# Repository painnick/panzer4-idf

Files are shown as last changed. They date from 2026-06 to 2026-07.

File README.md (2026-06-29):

# RC 탱크 프로젝트(Panzer IV)

Bluepad32를 이용한 게임패드 조작 RC 탱크입니다. ESP32-IDF(v5.5.2) 기반으로 개발되었습니다.

PCB는 KingTiger용을 사용합니다.

## 주요 기능

- **게임패드 연결**: Bluepad32를 통한 블루투스 게임패드 연결 및 상태 LED/진동 피드백
- **트랙 제어**: 좌측 스틱 Y축(좌측 트랙), 우측 스틱 Y축(우측 트랙) 독립 제어 (DRV8833, MCPWM, 엑스포 곡선, 가감속 램프, 대회전 감속)
- **터렛 제어**: D-PAD 좌우로 터렛 회전 (DRV8833, MCPWM, 최대 속도 100% 듀티)
- **포 마운트 제어**: D-PAD 상하로 포신 상하 이동 (SG90 서보, 80~110도, 초당 10도)
- **포신 발사**: B 버튼 클릭 시 포신 반동(서보 0->60->0), LED 점등, 발사 효과음 및 게임패드 진동 발생 (트랙 후진 반동 200ms 동기화)
- **기관총 발사**: A 버튼 클릭 시 기관총 LED 깜빡임(500ms), 효과음 및 게임패드 진동 발생 (반응성 개선을 위해 지연 시간 300ms로 단축)
- **헤드라이트**: Y 버튼으로 헤드라이트 ON/OFF 토글
- **볼륨 조절**: L1 버튼으로 감소, R1 버튼으로 증가 (NVS 저장, 10-30 범위)
- **대기 상태 알림**: 게임패드 연결 전/해제 후에는 30초마다 엔진 IDLE 효과음을 1회 재생하여 상태 알림 (연결 중에는 IDLE 소리 중지)
- **설정 초기화**: Select + Start 버튼을 3초간 누르면 볼륨 설정 초기화 및 재시작

## 하드웨어 구성

### ESP32 핀 맵

| ESP32 핀 | 기능 | 설명 |
| :--- | :--- | :--- |
| **GPIO 4** | 후미등 LED | Backlight |
| **GPIO 5** | 헤드라이트 LED | Headlight (Y 버튼 토글) |
| **GPIO 13** | 포 마운트 서보 | SG90 서보 - 포신 상하 이동 (80~110도) |
| **GPIO 16** | 기관총 LED | MG LED (A 버튼 클릭 시 깜빡임) |
| **GPIO 17** | 포신 LED | Gun LED (B 버튼 클릭 시 점등) |
| **GPIO 21** | 터렛 IN2 | DRV8833 - 터렛 회전 (MCPWM) |
| **GPIO 22** | 터렛 IN1 | DRV8833 - 터렛 회전 (MCPWM) |
| **GPIO 23** | 사운드 TX | DFPlayer Mini UART TX |
| **GPIO 25** | 우측 트랙 IN2 | DRV8833 - 우측 트랙 (MCPWM) |
| **GPIO 26** | 좌측 트랙 IN2 | DRV8833 - 좌측 트랙 (MCPWM) |
| **GPIO 27** | 좌측 트랙 IN1 | DRV8833 - 좌측 트랙 (MCPWM) |
| **GPIO 32** | 포신 서보 | 포신 반동 (Recoil) 제어 |
| **GPIO 33** | 우측 트랙 IN1 | DRV8833 - 우측 트랙 (MCPWM) |

### 모터 드라이버 (DRV8833) 연결

#### 트랙 드라이버
- **AIN (27, 26)**: 좌측 트랙 모터 (MCPWM)
- **BIN (33, 25)**: 우측 트랙 모터 (MCPWM)

#### 터렛 드라이버
- **AIN (22, 21)**: 터렛 회전 모터 (MCPWM, 최대 속도 100% 듀티)

### 서보 모터
- **GPIO 32**: 포신 반동 서보 (B 버튼 시 0도 -> 60도 -> 0도 동작)
- **GPIO 13**: 포 마운트 서보 SG90 (D-PAD 상하, 80~110도 범위, 초기 90도)

### 사운드 모듈 (DFPlayer Mini)
- **TX (GPIO 23)**: 모듈의 RX 핀에 연결하여 UART 제어 (9600bps)
- **RX (NC)**: 현재 수신 핀이 연결되지 않아 모듈 피드백(재생 종료 알림 등) 대신 타이머/하드웨어 루프 명령어로 상태 제어

---

## 게임패드 조작법

| 조작 | 기능 | 상세 동작 |
| :--- | :--- | :--- |
| **좌측 스틱 Y** | 좌측 트랙 | 위(전진), 아래(후진) |
| **우측 스틱 Y** | 우측 트랙 | 위(전진), 아래(후진) |
| **D-PAD 좌/우** | 터렛 회전 | 좌우 회전 (MCPWM, 최대 속도) |
| **D-PAD 상/하** | 포 마운트 | 상하 이동 (SG90 서보, 80~110도) |
| **A 버튼** | 기관총 발사 | 효과음 재생 + MG LED 깜빡임 |
| **B 버튼** | 주포 발사 | 효과음 재생 + Gun LED 점등 + 서보 반동 |
| **Y 버튼** | 헤드라이트 | ON / OFF 토글 |
| **L1 / R1** | 볼륨 조절 | 볼륨 감소 / 증가 (NVS 자동 저장) |
| **Select + Start** | 시스템 초기화 | 3초간 입력 시 설정 초기화 및 재부팅 |

---

## 소프트웨어 구조

### 주요 컴포넌트 (`components/rctank/`)
- `rctank_motor`: MCPWM을 이용한 트랙 및 터렛 제어
- `rctank_servo`: LEDC를 이용한 포신 반동 서보 및 포 마운트(SG90) 서보 제어
- `rctank_led`: 각종 LED 상태 제어
- `rctank_dfplayer`: DFPlayer Mini 제어 및 효과음 재생
- `rctank_storage`: NVS를 이용한 볼륨 및 설정값 저장

### 플랫폼 로직 (`main/my_flatform.c`)
- Bluepad32 이벤트 핸들링 및 게임패드 입력 맵핑
- **Core 1 오프로딩**: 게임패드 입력을 큐로 전달하여 Core 1에서 모터/서보/버튼 처리 (BT 컨트롤러 부하 경감)
- 발사 시퀀스 지연 보정 (Sound 재생 시점과 하드웨어 동작 동기화)
- 대회전 감속: 좌우 트랙 속도 차이가 클 때 전체 속도 비례 감소 (`TURN_SLOWDOWN_FACTOR`)

### 트랙 속도 제어 (`components/rctank/rctank_motor.c`)
- **엑스포 곡선**: 스틱 저속 구간(0~90%)에서 모터 속도를 완만하게, 고속 구간에서 급격하게 매핑하여 미세 조향 응답성 향상
- **가감속 램프**: 10ms 주기로 현재 속도를 목표 속도로 점진적 변화 (가속 600/sec, 감속 1000/sec)
- **최소 기동 속도**: 정지 상태에서 모터 기동 시 최소 토크 확보를 위한 오프셋 적용
- **감속 제자리 정지**: 감속 중 최소 속도 이하로 떨어지면 즉시 정지하여 모터 험 노이즈 방지

## 속도 제어 설정값

| 상수 | 값 | 위치 | 설명 |
| :--- | :--- | :--- | :--- |
| `AXIS_DEADZONE` | 60 | `my_flatform.c` | 조이스틱 데드존 (이 값 이하 무시) |
| `AXIS_MAX` | 512 | `my_flatform.c` | 조이스틱 최대 축 값 |
| `TURN_SLOWDOWN_FACTOR` | 60 | `my_flatform.c` | 대회전 시 최소 속도 비율 (60 = 60%) |
| `TRACK_DECEL_STEP` | 16 | `rctank_motor.c` | 10ms 당 감속 단계 (약 400ms 내 정지) |
| `TRACK_ACCEL_STEP` | 6 | `rctank_motor.c` | 10ms 당 가속 단계 (약 1000ms 내 최대 속도) |
| `TRACK_MIN_SPEED` | 448 | `rctank_motor.c` | 모터 최소 기동 속도 오프셋 |
| `TRACK_STICK_THRESHOLD` | 460 | `rctank_motor.c` | 엑스포 곡선 저속/고속 구간 경계 (90%) |
| `TRACK_EXPO_THRESHOLD` | 178 | `rctank_motor.c` | 경계값에서의 모터 속도 (약 35%) |

## 개발 환경 설정

1. **ESP-IDF v5.5.2** 설치
2. 프로젝트 루트의 `env.bat`를 실행하여 환경 변수 설정 (Windows)
3. `idf.py build` 명령으로 컴파일
4. `idf.py flash monitor` 명령으로 업로드 및 로그 확인

## 라이센스
MIT License

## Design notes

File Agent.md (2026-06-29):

# 프로젝트 컨텍스트: ESP32-IDF 기반 시스템 개발

이 파일은 AI 에이전트가 본 프로젝트의 구조, 스타일 가이드 및 기술적 의사결정 사항을 이해하기 위한 가이드라인입니다.

## 🛠 기술 스택
- **Framework:** ESP-IDF v5.5.2
- **Language:** C (C99/C11 표준 지향)
- **Build System:** CMake / idf.py. 루트의 env.bat를 먼저 실행하여 IDF 환경 설정을 반영해야 함 
- **Target Chip:** ESP32-기본

## 📂 프로젝트 구조
- `main/`: 메인 로직 및 `app_main.c` 위치
- `components/`: 재사용 가능한 사용자 정의 컴포넌트
- `managed_components/`: IDF Component Manager를 통해 추가된 라이브러리
- `sdkconfig`: ESP-IDF 구성 설정 파일

## 📝 코딩 스타일 및 규칙
1. **Naming Convention:**
    - 함수/변수: `snake_case` (예: `sensor_read_task`)
    - 컴포넌트 접두사: 함수명 앞에 컴포넌트 이름을 붙임 (예: `wifi_init_sta()`)
    - 상수/매크로: `UPPER_SNAKE_CASE`
2. **Error Handling:**
    - 모든 ESP-IDF API 호출 시 `esp_err_t` 리턴값을 확인하고 `ESP_ERROR_CHECK()` 또는 적절한 로그 처리를 수행할 것.
3. **Logging:**
    - `printf` 대신 `ESP_LOGI`, `ESP_LOGE`, `ESP_LOGW` 매크로를 사용할 것. (Tag는 파일 상단에 정의)
4. **FreeRTOS 활용:**
    - Task 생성 시 Stack Size와 Priority를 명시적으로 관리할 것.
    - 공유 자원 접근 시 `Mutex` 또는 `Semaphore` 필수 사용.

## 🔗 참조할 기존 코드 패턴 (Reference)
- **NVS 저장:** `components/storage/nvs_helper.c`의 패턴 사용
- **메모리 관리:** 정적 할당보다는 `pvPortMalloc` 또는 `heap_caps_malloc` 사용 선호

## ⚙️ 하드웨어 제어 규칙
- **DC 모터 구동:** 트랙 및 터렛 제어는 `MCPWM`을 사용함. 터렛 회전 속도 조절은 `my_flatform.c`의 `TURRET_SPEED` 매크로로 제어 (현재 최대 속도인 511로 설정됨).
- **서보 모터:** **`LEDC`**를 사용하여 제어할 것. 포신 반동(GPIO 32) 및 포 마운트(SG90, GPIO 13) 모두 LEDC 채널 0/1을 사용.
- **입력 처리 아키텍처:** 게임패드 입력은 `my_platform_on_controller_data`(Core 0, BT 태스크)에서 큐(`input_queue`)로 전달하고, `input_process_task`(Core 1)에서 모터/서보/버튼 처리를 수행함. Core 0의 BT 컨트롤러 부하를 경감하기 위함. 모터 함수(`rctank_motor_*_set`)는 뮤텍스 없이 volatile 변수에 직접 쓰며, `_immediate` 함수는 non-blocking(timeout 0)으로 동작함.
- **동기화:** `recoil_end_time`은 `portMUX_TYPE` 스프록으로 보호하여 Core 1과 타이머 콜백 간 안전하게 공유함.

## ⚠️ 주의 사항
- `sdkconfig`를 직접 수정하지 말고, 설정 변경이 필요하면 `menuconfig` 항목을 언급해줄 것.
- IDF 5.5.2 버전의 API를 사용할 것. 다른 버전은 고려하지 않고 있음
- **하드웨어 핀(Pin) 맵 및 상세 기능 정의는 프로젝트 루트의 `README.md` 파일을 최우선으로 참조할 것.**
- **리코일 사양:** 서보 각도는 0(Rest) ~ 60(Pull) 범위를 사용하며, 트랙 후진 반동 시간은 200ms를 유지함.
- **사운드 피드백 제약:** 사운드 모듈의 RX 핀이 연결되지 않은 상태이므로, `rctank_dfplayer`의 자동 복구 기능 대신 `main` 로직의 타이머나 모듈 자체 루프 명령을 사용하여 상태를 동기화함.

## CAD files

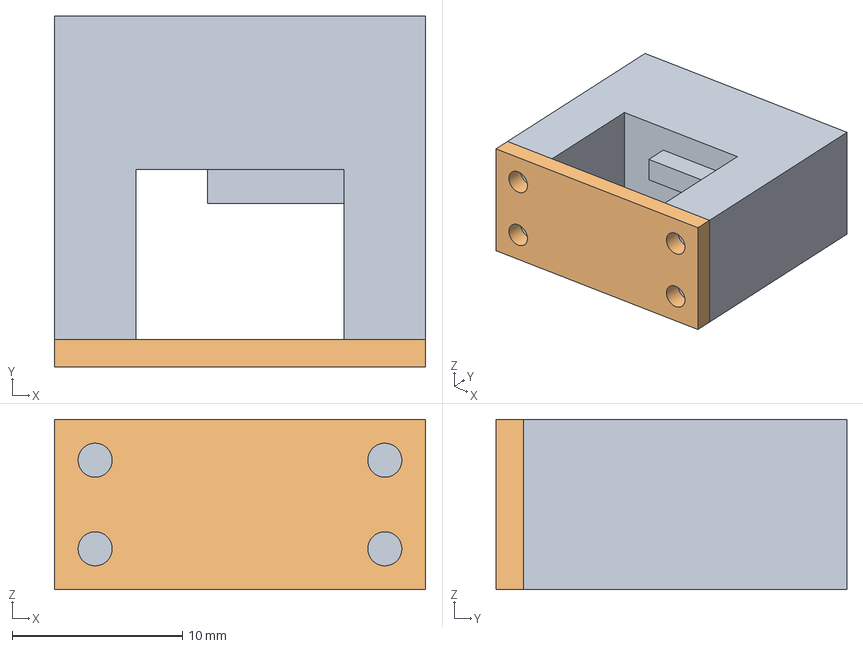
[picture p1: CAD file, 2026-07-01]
3dp/Turret Motor Guide2.step
21.8 x 20.6 x 10.0 mm

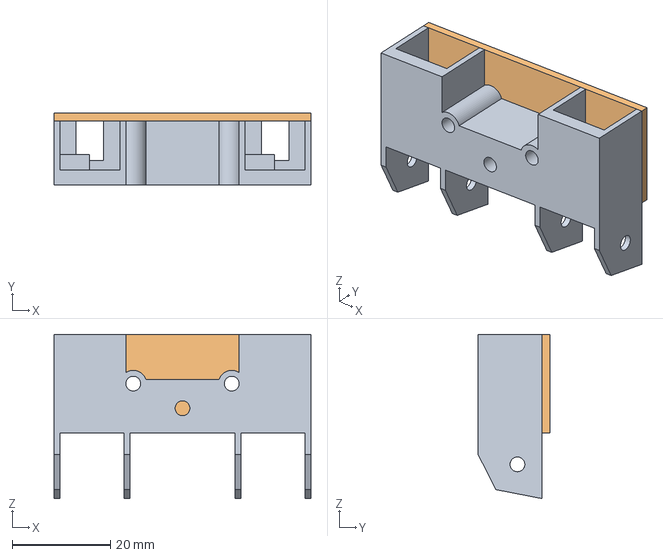
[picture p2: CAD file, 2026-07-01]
3dp/Sproket Guide.step
52.2 x 14.6 x 33.3 mm

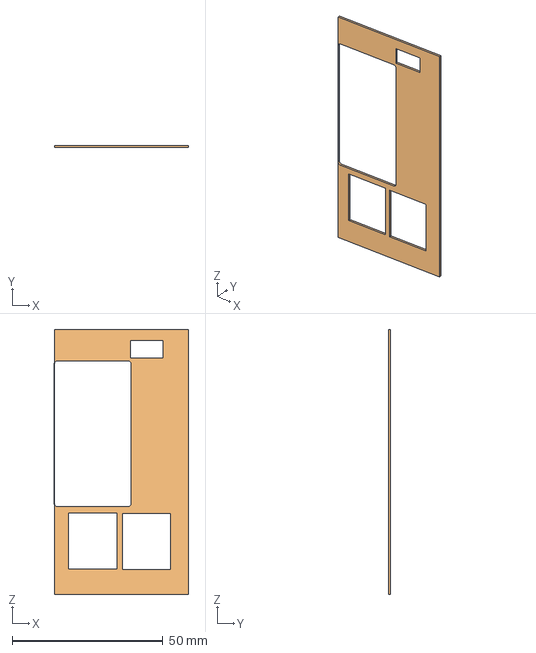
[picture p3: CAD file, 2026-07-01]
3dp/PCB 1.2.step
44.5 x 0.8 x 87.8 mm

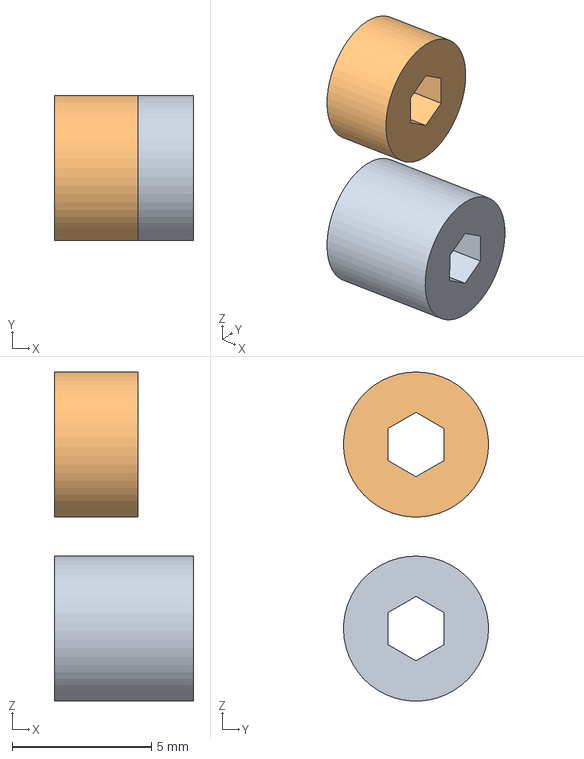
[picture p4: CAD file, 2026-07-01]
3dp/Motor Guide 2mm.step
5.00 x 5.20 x 11.8 mm

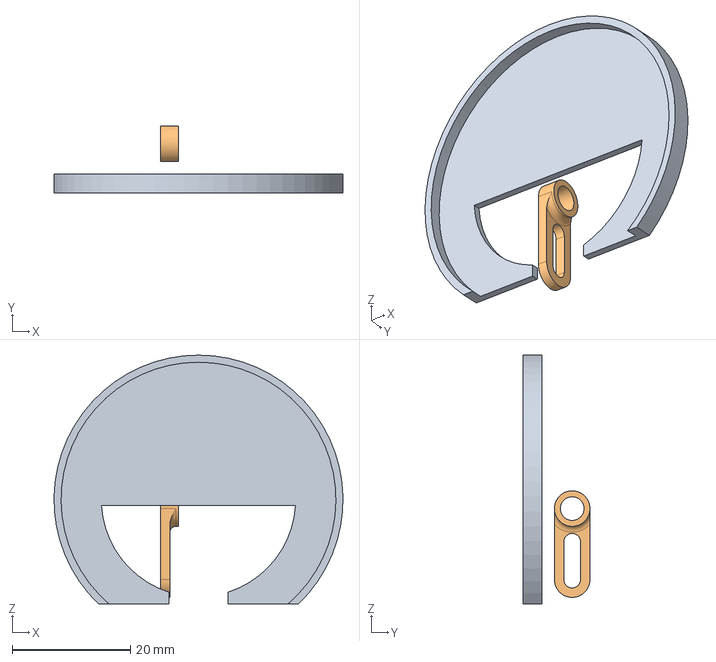
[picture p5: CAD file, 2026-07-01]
3dp/Cannon Mount.step
48.8 x 11.3 x 42.0 mm

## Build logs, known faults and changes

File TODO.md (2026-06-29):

# TODO

## ~컨트롤러 종류별 최대 입력 값 적용~

~각 컨트롤러마다 아날로그 입력 값의 최대치가 상이함~

~트랙 이동 속도에 영향을 주므로 비례 제어를 위해 컨트롤러 별 최대값 대응이 필요~

스틱 데드존을 뺀 나머지 입력 영역을 실제 트랙 이동 가능한 모터 듀티 범위와 비례하도록 처리

## 헤드 라이트 입력 조건 수정

안드로이드 게임 패드에서 L2/R2 입력 불가

PS3 무선 컨트롤러는 입력 가능

2025.12.07 우선 대응 버튼 변경

## 트랙 이동 시, 처음부터 최대값으로 이동하지 않도록 처리(Soft-start)

모터 구동 시 소모 전류가 급격하게 증가하여 극벽한 변화 시 Brownout 현상이 발생

그리고, 급출발이 현실적이지 않음

아래와 같은 아이디어가 존재

1. 500ms 내 일정 속도 이상 증가를 막는 방법
2. 기어 변속 같은 느낌으로 속도 제어
+
+## ✅ 완료된 작업
+
+### 리코일 및 기관총 시퀀스 튜닝 (2026.04.29)
+- 리코일 서보 동작 방향 반전 (90 -> 180 -> 90)
+- 트랙 반동 시간(300ms) 및 보호 로직(`recoil_end_time`) 적용
+- 기관총 발사 지연 시간(300ms) 및 점멸 시간(500ms) 최적화
+
+### 모터 제어 최적화
+- ESP32 MCPWM 자원 부족 문제 해결을 위해 터렛/포 마운트 모터를 GPIO 제어 방식으로 전환
+

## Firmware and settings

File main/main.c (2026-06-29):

// Example file - Public Domain
// Need help? http://bit.ly/bluepad32-help

#include <stdlib.h>

#include <btstack_port_esp32.h>
#include <btstack_run_loop.h>
#include <btstack_stdio_esp32.h>
#include <hci_dump.h>
#include <hci_dump_embedded_stdout.h>
#include <uni.h>

#include "sdkconfig.h"

// Sanity check
#ifndef CONFIG_BLUEPAD32_PLATFORM_CUSTOM
#error "Must use BLUEPAD32_PLATFORM_CUSTOM"
#endif

// Defined in my_platform.c
struct uni_platform* get_my_platform(void);

int app_main(void) {
    // If you enable HCI Dump better to disable "Bluepad32 USB Console" from "idf.py menuconfig".
    // hci_dump_init(hci_dump_embedded_stdout_get_instance());

    // Configure BTstack for ESP32 VHCI Controller
    btstack_init();

    // Must be called before uni_init()
    uni_platform_set_custom(get_my_platform());

    // Init Bluepad32.
    uni_init(0 /* argc */, NULL /* argv */);

    // Does not return.
    btstack_run_loop_execute();

    return 0;
}

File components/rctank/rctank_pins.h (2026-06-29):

/**
 * @file rctank_pins.h
 * @brief RC Tank 핀 정의 (README.md 기준)
 */
#ifndef RCTANK_PINS_H
#define RCTANK_PINS_H

#include "driver/gpio.h"

#ifdef __cplusplus
extern "C" {
#endif

/* LED */
#define RCTANK_PIN_GUN_LED (GPIO_NUM_17)
#define RCTANK_PIN_HEADLIGHT (GPIO_NUM_5)
#define RCTANK_PIN_MG_LED (GPIO_NUM_16) /* 기관총 LED (A 버튼, 1초간 깜빡임) */
#define RCTANK_PIN_BACKLIGHT (GPIO_NUM_4)

/* 좌측 트랙 DRV8833 (AIN1, AIN2) */
#define RCTANK_PIN_LEFT_IN1 (GPIO_NUM_27)
#define RCTANK_PIN_LEFT_IN2 (GPIO_NUM_26)

/* 우측 트랙 DRV8833 (BIN1, BIN2) */
#define RCTANK_PIN_RIGHT_IN1 (GPIO_NUM_33)
#define RCTANK_PIN_RIGHT_IN2 (GPIO_NUM_25)

/* 터렛 DRV8833 (MCPWM 제어) */
#define RCTANK_PIN_TURRET_IN1 (GPIO_NUM_22)
#define RCTANK_PIN_TURRET_IN2 (GPIO_NUM_21)

/* 포 마운트 서보 (SG90) */
#define RCTANK_PIN_SERVO_ELEVATION (GPIO_NUM_13)

/* 서보: 포신(당기기) */
#define RCTANK_PIN_SERVO_RECOIL (GPIO_NUM_32)

/* Sound (JQ6900/JQ6500) UART TX */
#define RCTANK_PIN_SOUND_TX (GPIO_NUM_23)
#define RCTANK_PIN_SOUND_RX (GPIO_NUM_NC)

#ifdef __cplusplus
}
#endif

#endif /* RCTANK_PINS_H */

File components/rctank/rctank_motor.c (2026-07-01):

/**
 * @file rctank_motor.c
 * @brief RC Tank MCPWM 트랙/터렛 제어
 */
#include "rctank_motor.h"
#include "rctank_pins.h"

#include "driver/mcpwm_prelude.h"
#include "esp_log.h"
#include "esp_check.h"

#include "freertos/FreeRTOS.h"
#include "freertos/task.h"
#include "freertos/semphr.h"

static const char *TAG = "rctank_motor";

#define MCPWM_FREQ_HZ          (20000)
#define MCPWM_RESOLUTION_HZ   (1000000)
#define MCPWM_PERIOD_TICKS    (MCPWM_RESOLUTION_HZ / MCPWM_FREQ_HZ)

/* 스틱 범위 ±512 → 듀티 비율 (0~100%) */
#define AXIS_MAX              512

#define TRACK_DECEL_STEP 16  // 10ms 당 감속 단계 (실질 범위 448~512에서 약 400ms 내에 정지, 10배 스케일)
#define TRACK_ACCEL_STEP 6   // 10ms 당 가속 단계 (실질 범위 448~512에서 약 1000ms 내에 최대 속도 도달, 10배 스케일)
#define TRACK_MIN_SPEED  448 // 모터 구동을 개시하는 최소 기동 속도 오프셋 (0~512 범위 내)
#define TRACK_STICK_THRESHOLD 460  // 90% 스틱 경계값 (512 * 0.90)
#define TRACK_EXPO_THRESHOLD  178  // 90% 경계값에서의 모터 중간 속도 목표치 (최대 속도의 약 91%가 되도록 조정)

static mcpwm_cmpr_handle_t left_cmpr_a = NULL;
static mcpwm_cmpr_handle_t left_cmpr_b = NULL;
static mcpwm_cmpr_handle_t right_cmpr_a = NULL;
static mcpwm_cmpr_handle_t right_cmpr_b = NULL;
static mcpwm_cmpr_handle_t turret_cmpr_a = NULL;
static mcpwm_cmpr_handle_t turret_cmpr_b = NULL;

static mcpwm_timer_handle_t timer0 = NULL;

static volatile int32_t target_left_speed = 0;
static volatile int32_t target_right_speed = 0;
static int32_t current_left_speed = 0;
static int32_t current_right_speed = 0;

static SemaphoreHandle_t motor_mutex = NULL;
static TaskHandle_t motor_task_handle = NULL;

static void set_motor_duty(mcpwm_cmpr_handle_t cmpr_a, mcpwm_cmpr_handle_t cmpr_b, int32_t speed);

static void update_motor_speed(int32_t *current, int32_t target)
{
    int32_t cur = *current;
    if (cur == target) {
        return;
    }

    // 1. 0에서 기동할 때 최소 구동 속도(TRACK_MIN_SPEED * 10)로 즉시 점프
    if (cur == 0 && target != 0) {
        int32_t sign = (target > 0) ? 1 : -1;
        int32_t start_speed = sign * TRACK_MIN_SPEED * 10;
        
        int32_t target_abs = (target > 0) ? target : -target;
        // target 절대값이 최소 기동 속도 이하이면 즉시 target으로 설정 후 리턴
        if (target_abs <= TRACK_MIN_SPEED * 10) {
            *current = target;
            return;
        }
        cur = start_speed;
        *current = cur;
    }

    int32_t diff = target - cur;
    int32_t step;

    // Determine if we are accelerating or decelerating
    bool is_decelerating = false;
    
    if (cur > 0) {
        if (target < cur) {
            is_decelerating = true;
        }
    } else if (cur < 0) {
        if (target > cur) {
            is_decelerating = true;
        }
    } else {
        is_decelerating = false;
    }

    if (is_decelerating) {
        step = TRACK_DECEL_STEP;
    } else {
        step = TRACK_ACCEL_STEP;
    }

    if (diff > 0) {
        if (diff > step) {
            *current = cur + step;
        } else {
            *current = target;
        }
    } else {
        if (-diff > step) {
            *current = cur - step;
        } else {
            *current = target;
        }
    }

    // 2. 감속 정지 시 최소 구동 속도 이하로 떨어지면 웅웅거림 방지를 위해 즉시 0으로 정지
    if (target == 0) {
        int32_t cur_abs = (*current > 0) ? *current : -*current;
        if (cur_abs < TRACK_MIN_SPEED * 10) {
            *current = 0;
        }
    }
}

static void rctank_motor_update_task(void *pvParameters)
{
    TickType_t last_wake_time = xTaskGetTickCount();
    while (1) {
        if (motor_mutex && xSemaphoreTake(motor_mutex, portMAX_DELAY) == pdTRUE) {
            update_motor_speed(&current_left_speed, target_left_speed * 10);
            if (left_cmpr_a && left_cmpr_b) {
                set_motor_duty(left_cmpr_a, left_cmpr_b, current_left_speed / 10);
            }

            update_motor_speed(&current_right_speed, target_right_speed * 10);
            if (right_cmpr_a && right_cmpr_b) {
                set_motor_duty(right_cmpr_a, right_cmpr_b, current_right_speed / 10);
            }
            xSemaphoreGive(motor_mutex);
        }
        vTaskDelayUntil(&last_wake_time, pdMS_TO_TICKS(10));
    }
}

static void set_motor_duty(mcpwm_cmpr_handle_t cmpr_a, mcpwm_cmpr_handle_t cmpr_b, int32_t speed)
{
    uint32_t ticks;
    if (speed > 0) {
        ticks = ((uint32_t)speed * MCPWM_PERIOD_TICKS) / AXIS_MAX;
        if (ticks > MCPWM_PERIOD_TICKS) ticks = MCPWM_PERIOD_TICKS;
        ESP_ERROR_CHECK(mcpwm_comparator_set_compare_value(cmpr_a, ticks));
        ESP_ERROR_CHECK(mcpwm_comparator_set_compare_value(cmpr_b, 0));
    } else if (speed < 0) {
        ticks = ((uint32_t)(-speed) * MCPWM_PERIOD_TICKS) / AXIS_MAX;
        if (ticks > MCPWM_PERIOD_TICKS) ticks = MCPWM_PERIOD_TICKS;
        ESP_ERROR_CHECK(mcpwm_comparator_set_compare_value(cmpr_a, 0));
        ESP_ERROR_CHECK(mcpwm_comparator_set_compare_value(cmpr_b, ticks));
    } else {
        ESP_ERROR_CHECK(mcpwm_comparator_set_compare_value(cmpr_a, 0));
        ESP_ERROR_CHECK(mcpwm_comparator_set_compare_value(cmpr_b, 0));
    }
}
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

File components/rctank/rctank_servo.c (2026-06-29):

/**
 * @file rctank_servo.c
 * @brief RC Tank LEDC 서보 제어
 */
#include "rctank_servo.h"
#include "rctank_pins.h"

#include "driver/ledc.h"
#include "esp_log.h"

static const char* TAG = "rctank_servo";

#define LEDC_TIMER LEDC_TIMER_0
#define LEDC_MODE LEDC_LOW_SPEED_MODE
#define LEDC_DUTY_RES LEDC_TIMER_10_BIT
#define LEDC_FREQ_HZ 50

#define SERVO_PULSE_MIN_US 500
#define SERVO_PULSE_MAX_US 2500
#define SERVO_DEGREE_RANGE 180

static uint32_t degree_to_duty(int degree) {
    if (degree < 0)
        degree = 0;
    if (degree > SERVO_DEGREE_RANGE)
        degree = SERVO_DEGREE_RANGE;
    uint32_t us =
        SERVO_PULSE_MIN_US + (SERVO_PULSE_MAX_US - SERVO_PULSE_MIN_US) * (uint32_t)degree / SERVO_DEGREE_RANGE;
    uint32_t max_duty = (1 << LEDC_DUTY_RES) - 1;
    return (us * LEDC_FREQ_HZ * max_duty) / 1000000;
}

esp_err_t rctank_servo_init(void) {
    ledc_timer_config_t timer_config = {
        .speed_mode = LEDC_MODE,
        .duty_resolution = LEDC_DUTY_RES,
        .timer_num = LEDC_TIMER,
        .freq_hz = LEDC_FREQ_HZ,
        .clk_cfg = LEDC_AUTO_CLK,
    };
    esp_err_t ret = ledc_timer_config(&timer_config);
    if (ret != ESP_OK) {
        ESP_LOGE(TAG, "ledc_timer_config %s", esp_err_to_name(ret));
        return ret;
    }

    ledc_channel_config_t ch_config = {
        .gpio_num = RCTANK_PIN_SERVO_RECOIL,
        .speed_mode = LEDC_MODE,
        .channel = LEDC_CHANNEL_0,
        .timer_sel = LEDC_TIMER,
        .duty = degree_to_duty(RCTANK_SERVO_GUN_DEG_REST),
        .hpoint = 0,
    };
    ret = ledc_channel_config(&ch_config);
    if (ret != ESP_OK) {
        ESP_LOGE(TAG, "ledc_channel_config recoil %s", esp_err_to_name(ret));
        return ret;
    }

    ledc_channel_config_t elevation_ch_config = {
        .gpio_num = RCTANK_PIN_SERVO_ELEVATION,
        .speed_mode = LEDC_MODE,
        .channel = LEDC_CHANNEL_1,
        .timer_sel = LEDC_TIMER,
        .duty = degree_to_duty(RCTANK_SERVO_ELEVATION_DEG_REST),
        .hpoint = 0,
    };
    ret = ledc_channel_config(&elevation_ch_config);
    if (ret != ESP_OK) {
        ESP_LOGE(TAG, "ledc_channel_config elevation %s", esp_err_to_name(ret));
        return ret;
    }

    rctank_servo_gun_set_degree(RCTANK_SERVO_GUN_DEG_REST);
    rctank_servo_elevation_set_degree(RCTANK_SERVO_ELEVATION_DEG_REST);
    ESP_LOGI(TAG, "servo init ok (recoil pin %d, elevation pin %d)", RCTANK_PIN_SERVO_RECOIL, RCTANK_PIN_SERVO_ELEVATION);
    return ESP_OK;
}

static int s_gun_degree = RCTANK_SERVO_GUN_DEG_REST;
static int s_elevation_degree = RCTANK_SERVO_ELEVATION_DEG_REST;

void rctank_servo_gun_set_degree(int degree) {
    if (degree < 0)
        degree = 0;
    if (degree > SERVO_DEGREE_RANGE)
        degree = SERVO_DEGREE_RANGE;
    s_gun_degree = degree;
    uint32_t duty = degree_to_duty(degree);
    ledc_set_duty(LEDC_MODE, LEDC_CHANNEL_0, duty);
    ledc_update_duty(LEDC_MODE, LEDC_CHANNEL_0);
}

void rctank_servo_gun_enable(int enable) {
    if (enable) {
        /* 저장된 각도로 duty 복원 */
        rctank_servo_gun_set_degree(s_gun_degree);
    } else {
        /* PWM 중지 -> 서보 힘 풀림 */
        ledc_stop(LEDC_MODE, LEDC_CHANNEL_0, 0);
    }
}

void rctank_servo_elevation_set_degree(int degree) {
    if (degree < RCTANK_SERVO_ELEVATION_MIN)
        degree = RCTANK_SERVO_ELEVATION_MIN;
    if (degree > RCTANK_SERVO_ELEVATION_MAX)
        degree = RCTANK_SERVO_ELEVATION_MAX;
    s_elevation_degree = degree;
    uint32_t duty = degree_to_duty(degree);
    ledc_set_duty(LEDC_MODE, LEDC_CHANNEL_1, duty);
    ledc_update_duty(LEDC_MODE, LEDC_CHANNEL_1);
}

void rctank_servo_elevation_enable(int enable) {
    if (enable) {
        rctank_servo_elevation_set_degree(s_elevation_degree);
    } else {
        ledc_stop(LEDC_MODE, LEDC_CHANNEL_1, 0);
    }
}

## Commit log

2026-06-29 fix: BT controller 안정성 개선 및 IDF 5.5.2 업그레이드
    - ESP-IDF 5.4.3 → 5.5.2 업그레이드
    - 게임패드 입력 처리를 Core 1(input_process_task)로 오프로딩하여
    BT 컨트롤러(Core 0) 부하 경감, WDT 트리거 및 ASSERT_PARAM 크래시 해결
    - 모터 함수 뮤텍스 제거 (volatile 직접 쓰기, non-blocking)
    - recoil_end_time 동기화에 portMUX_TYPE 스프록 사용
    - WDT 타임아웃 5초 → 15초로 증가
    - 문서(Agent.md, README.md)에 아키텍처 변경 반영
    [my_flatform.c]
2026-07-01 UPDATE. 3dp
    [Cannon Mount.step, Gearbox2.step, King Tiger.3mf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]
